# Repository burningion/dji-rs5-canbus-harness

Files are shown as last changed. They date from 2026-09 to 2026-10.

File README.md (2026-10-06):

# DIY RS5 side-port CAN connector - prewired Mill-Max prototype

Build a removable spring-contact adapter on the RS5's electrical RSA/NATO port, with the battery grip attached. The design uses the **prewired Mill-Max 889-22-008-70-501010**, held between two printed parts. The RS5 adaptation retains this part; no different contact block is indicated by the compatibility evidence below. Use an ESP32 with a 3.3 V CAN transceiver, powered from USB for the first version.

**Status: the Mill-Max interface and wired UWB tracking work on the user's RS5.** Confirmed by the user on 2026-10-04: the direct `UWB anchor → ESP32 → Waveshare → Mill-Max pin harness → RS5` connection successfully tracked the tag. The new two-ESP32 wireless path is implemented and software-tested; pairing and following over that radio link still need a hardware check. Camera-enclosure fit, combined-battery operation and charging remain separate, unverified work.

Mill-Max dimensions come from its family drawing; nominal mounting geometry comes from the RS2 community design. The reference pinout, voltage and detect-resistor details below come from DJI R SDK v2.5's RS2 illustration. The working RS5 setup establishes this build's interface, but is not a measurement of accessory VCC or every mechanical tolerance. Keep the proven harness wiring and termination when adding wireless.

Geometry validation: base and cover each export as one closed solid; the combined print plate contains two closed solids. OpenSCAD's solid intersection between the assembled holder and the nominal Mill-Max connector envelope is empty (no solid interference). See [mesh checks](design/mesh-checks.json). This check covers the nominal connector geometry, not the RS5 or manufacturing tolerances.

## UWB through the camera and RS5 ESP32s

The intended wireless path is implemented, with the **RS5-body ESP32 as master** and the camera ESP32 as an optional UWB peripheral:

```text
Subject tag --UWB--> camera-mounted STM32 anchor
  --short UART TXD1/GND--> camera ESP32 (rs5_anchor_radio)
  --paired ESP-NOW radio--> RS5-body ESP32 (rs5_wireless_control)
  --GPIO5 TX / GPIO6 RX--> Waveshare SN65HVD230
  --CAN-H / CAN-L--> Mill-Max harness --> RS5
```

The camera ESP32 reads the anchor on **RX/GPIO38 at 115200 baud** and relays measurements. The body ESP32 runs the existing tracking controller and sends DJI commands over **1 Mbit/s CAN**. ESP-NOW needs no router. Move the anchor's UART/ground connection to the camera ESP32; keep the working body-side Waveshare/Mill-Max circuit. The camera and body have separate power, with no UART, power or ground cable crossing the moving axes. See [wireless wiring and power](firmware/WIRELESS_UWB.md).

The master polls the paired camera every 50 ms and owns tag selection, tracking, motion limits and all CAN commands. Manual mouse/PS4 control works with the camera off, absent, or not yet paired. After the one-time pairing below, powering the camera and tag automatically makes their reports available to the master; no body reflash or mode change is needed on each connection. Control Desk shows **NO UWB**, **TAG DETECTED**, then **TAG LIVE** once the selected tag has a valid fix. Detection offers follow but never starts it or takes over manual control. Losing UWB stops active follow; manual control remains available, and recovery requires a fresh follow action.

**The body still uses USB to the existing Control Desk.** It boots disarmed; apply your tag settings, wait for TAG LIVE, then press PS4 **X** or **Start UWB follow**. This firmware does not start autonomous follow when powered on. The camera ESP32 can run without a USB host. The Makerfabs anchor and tag keep their existing factory firmware and binding.

## Flash both ESP32s

Both targets are **Adafruit Feather ESP32-S3, 8 MB flash / No PSRAM**, using **esp32 by Espressif Systems 3.3.11**. Keep the full repository layout because the sketches include shared files.

| Physical board | Sketch to flash |
| --- | --- |
| On the moving camera, beside the UWB anchor | [rs5_anchor_radio.ino](firmware/rs5_anchor_radio/rs5_anchor_radio.ino) |
| On the RS5 body: master, connected to Waveshare CAN | [rs5_wireless_control.ino](firmware/rs5_wireless_control/rs5_wireless_control.ino) |
| Original single-ESP32 wired setup, if restoring it | [rs5_manual_control.ino](firmware/rs5_manual_control/rs5_manual_control.ino), on the body ESP32 |

**First-time pairing takes two uploads per ESP32:** first discover their MAC addresses, then generate the shared pairing file and rebuild/upload both. Without `firmware/shared/WirelessConfig.h`, both wireless sketches run for MAC discovery with `radio_ready=0`; UWB radio operation is disabled. If that file already exists for these exact two boards, keep it and go directly to the configured builds/uploads.

### 1. Prepare the tools and identify the ports

Run commands from the repository root. With [Arduino CLI installed](https://arduino.github.io/arduino-cli/latest/installation/), install the tested core if needed:

```sh
arduino-cli core update-index --additional-urls https://espressif.github.io/arduino-esp32/package_esp32_index.json
arduino-cli core install esp32:esp32@3.3.11 --additional-urls https://espressif.github.io/arduino-esp32/package_esp32_index.json
arduino-cli board list
```

Connect each Feather through its own USB-C connector, one at a time, and label it **camera** or **body**. Replace `CAMERA_FEATHER_PORT` and `BODY_FEATHER_PORT` below with their actual ports (for example `/dev/cu.usbmodem...` on macOS). Do not select the Makerfabs anchor's port. Close Control Desk's serial connection and any serial monitor before uploading. For flashing, leave the RS5 powered off; neither sketch automatically starts motion.

### 2. Build, flash and read each MAC address

**Camera ESP32:**

```sh
arduino-cli compile \
  --fqbn esp32:esp32:adafruit_feather_esp32s3_nopsram --warnings all --clean \
  --build-path "$PWD/tmp/build-rs5_anchor_radio" \
  --output-dir "$PWD/tmp/rs5_anchor_radio" firmware/rs5_anchor_radio
arduino-cli upload \
  --fqbn esp32:esp32:adafruit_feather_esp32s3_nopsram \
  --port CAMERA_FEATHER_PORT --input-dir "$PWD/tmp/rs5_anchor_radio" \
  firmware/rs5_anchor_radio
arduino-cli monitor --port CAMERA_FEATHER_PORT --config baudrate=115200
```

Record the `camera mac=AA:BB:CC:DD:EE:FF` address printed once per second. Close the monitor with Ctrl+C.

**RS5-body ESP32:**

```sh
arduino-cli compile \
  --fqbn esp32:esp32:adafruit_feather_esp32s3_nopsram --warnings all --clean \
  --build-path "$PWD/tmp/build-rs5_wireless_control" \
  --output-dir "$PWD/tmp/rs5_wireless_control" firmware/rs5_wireless_control
arduino-cli upload \
  --fqbn esp32:esp32:adafruit_feather_esp32s3_nopsram \
  --port BODY_FEATHER_PORT --input-dir "$PWD/tmp/rs5_wireless_control" \
  firmware/rs5_wireless_control
arduino-cli monitor --port BODY_FEATHER_PORT --config baudrate=115200
```

Type `help` and press Enter. Record the `body mac=AA:BB:CC:DD:EE:FF` address, then close the monitor. These are the **Wi-Fi STA MAC addresses**, not UWB tag IDs or Bluetooth addresses. USB ports can change after flashing; run `arduino-cli board list` again and update the port if needed.

### 3. Pair, then rebuild and flash both again

Replace the MAC placeholders with the two recorded addresses:

```sh
python3 tools/configure_wireless_pair.py --camera CAMERA_STA_MAC --body BODY_STA_MAC
```

This creates ignored `firmware/shared/WirelessConfig.h` with the peer addresses, random encryption keys and channel 6. It refuses to overwrite an existing pairing. Keep this file for subsequent updates to the same pair; only move it aside deliberately when replacing/re-pairing boards. Both builds must use the same file.

**Repeat both compile/upload blocks from step 2 after generating the file.** The `--clean` builds ensure the new pairing configuration is included. Uploading the earlier discovery binaries again will leave the radios disabled.

### 4. Verify the link and enable follow

With both nodes powered, check camera serial output for `radio_ready=1`. In the body's JSON status, the `uwb` object should contain `"transport":"esp-now"` and `"radio_ready":true`. These flags confirm local radio initialization; live tag reports on the body prove measurements cross the wireless link.

Close the serial monitors, power the RS5, and start the existing UI:

```sh
python3 control_ui/server.py
```

Open **http://127.0.0.1:8765**, connect to the **body** ESP32, wait for LIVE RS5 angles, apply your tag ID/direction/offset and **5°/s** follow speed, then wait for **TAG LIVE**. Press PS4 **X** or **Start UWB follow**. Retain the settings that worked in the wired test; confirm the camera turns toward the tag. Test camera power loss/tag loss: follow should stop and require a fresh enable action after reports return. [Control Desk setup and controls](control_ui/UWB_SETUP.md#controls-and-first-follow-test).

### Arduino IDE and upload recovery

In Arduino IDE, install **esp32 by Espressif Systems 3.3.11**, then open the camera or body `.ino` from the table. Select **Adafruit Feather ESP32-S3 No PSRAM** and its USB port. Keep **8MB**, **QIO 80MHz**, **TinyUF2 8MB (2MB APP/3.7MB FATFS)**, **USB-OTG (TinyUSB)**, **USB CDC On Boot: Enabled**, and **Upload Mode: USB-OTG CDC (TinyUSB)**. Upload each discovery sketch and use Serial Monitor at **115200**, with a newline for the body's `help` command. Generate the pairing file with the Python command above, then compile/upload both again; the CLI `--clean` commands above provide a clean rebuild after adding the file.

If a Feather has no upload port, hold **BOOT**, tap **RESET**, release **BOOT**, then select its new port. For CLI upload from the ROM bootloader, add `--board-options UploadMode=default` to the upload command if the TinyUSB reset step fails. Press RESET after uploading from ROM mode, then rediscover the application port. [Adafruit's native-USB upload/recovery guide](https://learn.adafruit.com/adafruit-esp32-s3-feather/using-with-arduino-ide).

## When and how to control the RS5

**Mouse and PS4 control remain built into Control Desk.** The current control path is `mouse / PS4 → Mac browser → USB → RS5-body ESP32 master → Waveshare → Mill-Max → RS5`. The camera ESP32 adds optional UWB measurements; manual control works with it powered off.

1. Power the RS5 and connect the **body ESP32** to the Mac by USB. Run `python3 control_ui/server.py`, open **http://127.0.0.1:8765**, select its port and click **Connect**. Wait for **LIVE** RS5 angles. Keep the browser page visible and focused while controlling.
2. For PS4 control, connect the DualShock 4 to the **Mac** with a USB data cable, or hold **SHARE + PS** until its light flashes and select **DUALSHOCK 4 Wireless Controller** in macOS Bluetooth settings. Click the browser page, press a controller button, then release L1 and X before starting. [Detailed controller setup](control_ui/README.md#pair-the-ps4-controller).
3. Use the controls below. Detection, connection and power-up never start movement; each start needs a fresh operator action.

| Action | When available | How to use it |
| --- | --- | --- |
| Mouse pan/tilt | LIVE RS5 angles; UWB is optional | Hold/drag the pad or hold a direction button; release to stop |
| PS4 pan/tilt | LIVE RS5 angles and controller detected | Hold **L1 + left stick**; release L1 to stop |
| UWB pan follow | Applied tag settings and **TAG LIVE** | Press **X** or **Start UWB follow**; press again to stop |
| Stop | During manual control or follow | **Circle**, **Space**, or **Escape** |
| Change from follow to manual | During follow | L1 or mouse cancels follow; release, then hold again to steer |
| Restart after a lost tag or connection | Connection restored; TAG LIVE again for follow | Release controls, then make a fresh manual gesture or X/button press; no automatic restart |

The manual speed slider is **1–60°/s**, initially **10°/s**. UWB follow has its own **1–30°/s** limit, initially **5°/s**, and controls pan only. For UWB, power the paired camera node and tag, enter the detected short tag ID, apply direction/center/speed settings, and wait for TAG LIVE. **TAG DETECTED alone does not enable follow.** Settings must be reapplied after a body reset or page reload. Start with a small tag offset and verify steering toward it. [UWB setup, calibration and controls](control_ui/UWB_SETUP.md#controls-and-first-follow-test).

To use the expanded 30°/s follow range, rebuild/reflash the **body ESP32**, restart the Control Desk server and reload the page. Older body firmware rejects settings above 15°/s; the camera relay needs no change. Preserve the pair's existing configuration when rebuilding. The former ceiling was a conservative bench-test setting; the starting value remains 5°/s. [Speed setting and update details](control_ui/UWB_SETUP.md#tracking-behavior).

The current firmware requires the active USB/Control Desk session for both manual control and follow. Closing/hiding the page, losing focus, or losing controller/input/USB communication stops motion; returning does not resume it automatically.

### Future direct PS4 pairing

**Direct PS4-to-ESP32 Bluetooth control is not implemented.** The present Feather **ESP32-S3 cannot pair natively with a DualShock 4**: the controller uses Bluetooth Classic (BR/EDR), while the S3 supports Bluetooth LE only. This needs different/additional radio hardware, not just a pairing setting. [Bluepad32 compatibility explanation](https://bluepad32.readthedocs.io/en/latest/FAQ/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), [Espressif S3 Bluetooth support](https://docs.espressif.com/projects/esp-idf/en/stable/esp32s3/api-reference/bluetooth/index.html).

For a future extension that keeps the working S3/CAN master, add an **original ESP32 with Bluetooth Classic**, running Bluepad32 as a gamepad receiver, and pass its input to the master over a short local UART connection. Another option is to replace the body board with an original ESP32 and port the firmware/pin mapping. The existing S3 binaries cannot be flashed onto that replacement. These are proposed designs, not existing firmware features.

Either approach needs firmware support for controller pairing and input, local tag/settings management, and choosing between UI and direct-controller input. The master should retain L1-to-move, X-to-toggle-follow, Circle-to-stop, input timeouts and explicit restart after disconnection. Computer-free operation also needs a direct-controller input lease in place of today's required USB/browser lease; simply removing that requirement would not implement controller-loss handling. The camera remains an optional UWB peripheral. [More on future direct control](control_ui/README.md#future-direct-ps4-control).

## Changes from RS2

- **Use the one electrical RSA/NATO port.** The RS5 manual identifies it as item 17, next to the joystick-mode switch (item 25). The other side's NATO rail, item 12 near the power button, has no charging or communication. Identify the exposed contacts rather than relying on an ambiguous left/right description.
- **Retain Mill-Max 889-22-008-70-501010 and the ESP32/CAN-transceiver circuit.** DJI lists the same Focus Wheel, supplied with two M4 screws, for RS2 and RS5. That is strong evidence of a compatible legacy RSA interface; it is not a dimensional drawing for this DIY part.
- **No evidenced geometry change.** The RS5 base and cover deliberately retain revision-B dimensions. The new RS5 files, fit gauge and port instructions make that carry-over explicit. Confirm 19.85 mm nominal screw spacing, eight-pad alignment, pad recess, screw depth and cable-ear clearance on your RS5; those values were not measured on one here.
- **Keep USB power for the controller.** Leave both accessory VCC leads insulated. The older SDK's 8 V accessory output is not an RS5-specific voltage guarantee; the RS5 battery's 11.2-17.8 V specification is a different circuit.
- **The electrical port is occupied by this adapter.** The RS5 Electronic Briefcase Handle cannot use that same mounting point simultaneously. DJI's special warning about fitting that new handle to older gimbals does not change the legacy Focus Wheel compatibility evidence.

## Files

- [Wireless camera-to-body electronics](firmware/WIRELESS_UWB.md): camera-side STM32 anchor plus its own Feather ESP32-S3 share one 3.7 V / 500 mAh battery; paired ESP-NOW sends measurements to the body-side Feather/CAN controller. Includes firmware, Feather USB charging, a direct positive-lead battery switch and pairing instructions. Revision G models the stacked Feather/STM32 mounts and Feather charging port; charging with the anchor load and other hardware behavior remain unverified.

- [Print both parts](design/rs5-millmax-print-plate.stl): base and rear cover, already oriented for printing at 100% scale in millimeters.
- [Base STL](design/rs5-millmax-base.stl) and [rear cover STL](design/rs5-millmax-cover.stl), if printing separately.
- [RS5 OpenSCAD entry point](design/rs5-millmax.scad), using [shared adjustable geometry](design/rsa-millmax.scad): select `assembly` or `exploded` for inspection. Requires OpenSCAD 2021.01 or newer.
- [1.2 mm fit gauge](design/rs5-fit-gauge.stl): print first; hold against the unpowered port by hand, without contacts or screws. It checks the footprint and alignment, not pad depth or preload.
- [Prototype preview](design/carrier-preview.png): base, cover, and assembled connector.
- [RS5 carrier alias](design/rs5-carrier.stl) is the same two-part print plate. The original [RS2 entry point](design/rs2-millmax.scad) and RS2 STLs remain available; the default holder geometry is unchanged.
- [Archived PRECI-DIP design](design/archive/rs2-precidip-rev-a.scad): superseded; its dimensions are not for Mill-Max.
- [Original community STL](references/rileyharmon-rs2-connector.stl): provenance for the mounting dimensions only.
- [RS5 wiring diagram](design/wiring.png), with the inherited-pinout limitation marked.
- [Feather ESP32-S3 CAN test firmware](firmware/README.md): Arduino listen-only monitor, GPIO5 TX / GPIO6 RX, serial diagnostics and flashing instructions for the Adafruit 8 MB / no-PSRAM board.
- [Finite RS5 motion bench test](firmware/rs5_can_motion_test/README.md): telemetry-gated three-cycle pan test, verified on the connected RS5 on 2026-09-28; no automatic motion on boot.
- [RS5 Control Desk](control_ui/README.md): local mouse / PS4 controller UI with **X-to-toggle UWB follow** ([connection layout and setup](control_ui/UWB_SETUP.md)) for analog pan and tilt, 1–60°/s speed selection with no added travel limits, live angles, and automatic hold-to-move with release-to-stop; companion [manual-control firmware](firmware/rs5_manual_control/README.md).
- [Standalone Makerfabs UWB camera-tracking prototype](firmware/rs5_uwb_tracker/README.md): camera-mounted AoA anchor, subject-carried tag, UART on Feather RX/GPIO38; preview by default, optional manually armed RS5 pan control. Compiled and host-tested; physical operation remains unverified.
- [Makerfabs tag pocket enclosure](design/mauwb-tag/README.md): revision D adds the anchor's exact 13.5 × 8.4 mm rocker opening on the BAT-connector side, with a switch fit coupon. Same case dimensions; rev C rear cover and battery shield can be reused. Removable 500 mAh battery, external charging, no soldered headers. Vendor PCB dimensions with provisional component heights.
- [Camera-top UWB anchor enclosure](design/mauwb-anchor/README.md): revision G mounts the Feather below the STM32/antenna, adds Feather USB-C access, and preserves the exact 13.5 × 8.4 mm rocker opening and 26.48 mm cage-hole spacing. Both boards have rear M2 screw mounts; Feather front pins and STM32 front-edge keepers provide support. Body 87.7 × 58 × 41.1 mm, overall height 72.81 mm. The rocker switches battery positive directly. **Physical fit/RF and charging with the anchor load are unverified.**
- [RS5 port illustrations](references/dji-rs5-ports.png) and [overview](references/dji-rs5-overview.png), from pages 17 and 6 of the [RS5 user manual](references/dji-rs5-user-manual.pdf).
- [DJI's illustrated pinout](references/dji-sdk-pinout.png), from PDF page 21 / printed page 19 of the [SDK](references/dji-r-sdk-v2.5.pdf).

## Electrical design

The user's Waveshare/Mill-Max wiring has already worked for RS5 control and wired tag tracking. Preserve that harness. For a new or rebuilt harness, identify every contact before applying power; the reference below is inherited from the older SDK, and a fit gauge cannot identify electrical signals.

The inherited RSA contact layout has **eight pads in two rows of four**; check this against the exposed RS5 port. DJI assigns six signal numbers because power and ground each appear twice. The numbers below are DJI's signal labels, not sequential positions in an eight-pin header.

| DJI label | Signal | Connection in this build |
| --- | --- | --- |
| 1, two pads | VCC, nominal 8 V in the older SDK | Leave disconnected; individually insulate both unused wire ends |
| 2 | CAN-L | CAN-L on the transceiver |
| 3 | SBUS_RX | Leave disconnected |
| 4 | CAN-H | CAN-H on the transceiver |
| 5 | AD_COM | 47 kOhm resistor to ground at the controller's terminal block |
| 6, two pads | GND | Transceiver ground and ESP32 ground; one ground contact suffices for this signal-only build |

DJI specifies a 10-100 kOhm accessory-detect pull-down; 47 kOhm is our choice within that range. The SDK explicitly links detection to enabling port power. It does not establish that the resistor is necessary for CAN alone. Do not substitute a direct short.

The **legacy RS2 SDK illustration**, viewed facing the gimbal contacts in its illustrated orientation, gives this arrangement. This is a reference for tracing signals, not a verified upright view of the RS5:

```text
        GND       AD_COM     SBUS_RX     8 V
        GND       CAN-H      CAN-L       8 V
```

Use the [illustrated DJI reference](references/dji-sdk-pinout.png) to understand its viewing direction. Do not transfer its pictured RS2 body orientation directly to RS5. The older SDK's remark about two rotationally symmetric side ports applies to RS2; RS5 has only one electrical RSA port. Confirm the RS5 ground column against a known ground with the battery and USB disconnected; if orientation cannot be established, stop before energizing and obtain an RS5-specific reference. The adapter's mating face also reverses left/right relative to a face-on view of the gimbal. Mark the ground column and identify each wire by continuity to its contact. The Mill-Max wires are all black; do not infer signal identity from wire color or the order of the loose ends.

Recommended controller interface:

```text
ESP32 TWAI TX ---- transceiver D / TXD
ESP32 TWAI RX <--- transceiver R / RXD
ESP32 3V3 ------- transceiver VCC
ESP32 GND ------- transceiver GND ------- RS5 GND
                  transceiver CANH ------ RS5 CAN-H
                  transceiver CANL ------ RS5 CAN-L

RS5 AD_COM ------- 47 kOhm ------- RS5 GND
```

An SN65HVD230 breakout is suitable: it operates from 3.3 V and supports 1 Mbit/s. Use high-speed mode (RS low, per TI's datasheet), local supply decoupling, and check whether the module already contains a termination resistor. ESP32 GPIOs cannot connect directly to CAN-H/L. ESP32's built-in TWAI controller supplies the controller function; the transceiver supplies the electrical interface. Select GPIOs appropriate to your particular ESP32 board. A classic Arduino Uno instead needs a CAN controller as well as a transceiver.

For the **Adafruit Feather ESP32-S3, 8 MB flash / no PSRAM**, all body-side sketches use **pin 5 (GPIO5) to Waveshare CAN TX** and **pin 6 (GPIO6) from Waveshare CAN RX**, with the Feather's 3V output and common GND. GPIO4 is the Feather's I2C SCL line and is left available for its onboard devices and STEMMA QT. The [CAN monitor](firmware/README.md) is a passive diagnostic; the wired and wireless control sketches use normal 1 Mbit/s CAN and send DJI commands when operated through Control Desk.

The connector has approximately 203 mm (8 inches) of 24 AWG leads. Identify and gently twist the CAN-H/L pair, keeping a short transition at the connector. Run ground alongside the pair. The detect lead goes to a terminal with the 47 kOhm resistor to ground. Bare lead ends can connect to a suitable screw-terminal CAN breakout; the pogo block itself needs no soldering or crimping. Anchor the insulated wires to the rear cover's cable-tie ear, allowing a gentle bend after they leave the holes. Individually insulate unused leads.

## Parts

| Quantity | Part | Selection notes |
| --- | --- | --- |
| 1 each | Printed base and rear cover | PLA for fit checks; PETG or ASA for the working parts |
| 1 | Mill-Max 889-22-008-70-501010 | Prewired, 8 contacts, 2x4, 2.54 mm grid; Mouser stock number 575-8892200870501010 |
| 2 | M4 screws and small washers | Both layers total 11.85 mm nominal, plus washers; choose length after measuring RS5 thread depth |
| 1 | 47 kOhm resistor | Accessory detect to ground |
| 1 | SN65HVD230 breakout | 3.3 V supply, high-speed mode, accessible termination |
| 1 | ESP32 development board | USB powered initially |
| 1 | 120 Ohm resistor and jumper | Fit only if required by the measured bus termination |
| As needed | Terminal connections, insulating sleeves/heat-shrink, small cable tie | No glue is required to retain the pogo block |

Order link: [Mill-Max 889-22-008-70-501010 at Mouser](https://www.mouser.com/ProductDetail/Mill-Max/889-22-008-70-501010?qs=Rp5uXu7WBW9JMC9qfc9GZw%3D%3D). The 889-22 version has spring contacts; the 889-10 version is a different target-contact product.

The rear cover captures the plastic housing and encloses each exposed rear metal section in its own tunnel. All eight wires pass straight through the cover. The housing is retained by the two M4 mounting screws through both printed layers. The locating pins align the cover; they do not carry the spring load.

## Mill-Max dimensions used

See the [manufacturer's family drawing](references/millmax-889-family.pdf) and [enlarged detail](references/millmax-889-drawing-detail.png). The PDF title names the 14-position part; the drawing is explicitly for **889-22-0XX-70-501010** and gives housing length as `number of pins x 0.100 inch / 2`. Applying that formula to 8 contacts gives 10.16 mm. The drawing's inch dimensions are used in CAD to avoid accumulating rounding differences.

| Feature | Drawing dimension | CAD value |
| --- | --- | --- |
| Contact pitch and row pitch | 0.100 in | 2.540 mm |
| Housing length, eight contacts | 8 x 0.100 in / 2 | 10.160 mm |
| Housing width | 0.200 in | 5.080 mm |
| Housing thickness | 0.110 in | 2.794 mm |
| Tip to rear shoulder | 0.283 in | 7.1882 mm |
| Rear shoulder to start of wire insulation | 0.158 in | 4.0132 mm |
| Housing rear to start of wire insulation | 0.204 in, +/-0.010 | 5.1816 mm, +/-0.254 |
| Tip diameter / front fixed barrel | 0.042 / 0.059 in | 1.067 / 1.499 mm |
| Rear shoulder / crimp barrel diameter | 0.067 / 0.062 in | 1.702 / 1.575 mm |
| Maximum spring stroke | 0.055 in | 1.397 mm |

**The 7.19 mm dimension is not measured from the plastic housing's back face.** The correct tip-to-housing-rear distance is `7.1882 + 4.0132 - 5.1816 = 6.0198 mm`. This distinction matters when setting spring compression. The fixed front barrels also need larger holes than the earlier PRECI-DIP tip apertures.

## Mechanical design and fit

The original STL measures approximately 19.80 x 28.85 x 8.00 model units, with 4.3 mm mounting bores about 19.85 mm apart. STL does not encode units; use millimeters as a starting assumption. These are measurements of a community mesh, **not a DJI dimensioned drawing**. The original mesh passed an edge-sharing check for a closed surface.

The RS5 prototype keeps the revision-B mounting footprint but uses a 5.420 mm base plus a 6.432 mm rear cover, approximately **11.85 mm total**. The optional cable-tie ear adds 9 mm to one side of the cover; maximum width is 28.80 mm with the ear enabled. Check its clearance on the RS5; `strain_relief_ear=false` produces a compact 19.80 mm-wide cover.

When mounted and the contacts are loaded, the rear of the connector's plastic housing rests against the cover's inner face. That face sets the spring preload. The front pocket has 0.20 mm axial clearance so the cover does not squeeze a slightly oversize housing. The block can move forward slightly while unmounted; this is intentional. Tighten the M4 screws only enough to close the printed layers and seat the holder, not to compress the plungers to their limit.

Important parameters in `design/rsa-millmax.scad` (or override using OpenSCAD `-D`):

| Parameter | Default | What to verify |
| --- | --- | --- |
| `mount_pitch` | 19.85 mm | Actual M4 hole center spacing |
| `contact_offset_x/y` | 0.02 / 0.22 mm | Contact-array center relative to mounting-hole midpoint |
| `pad_recess` | 0 mm placeholder | Distance from carrier support surface down to contact-pad surface |
| `target_compression` | 0.60 mm | Engineering starting target, subject to actual contact travel and tolerances |
| `pocket_clearance` | 0.40 mm total | Actual pocket fit around the housing, allowing its +/-0.13 mm dimensional tolerance |
| `front_aperture_diameter` | 1.95 mm | Printed holes clear the fixed 1.50 mm front barrels |
| `wire_tunnel_diameter` | 2.10 mm | Printed holes clear rear shoulders and actual wire insulation |
| `axial_clearance` | 0.20 mm | Forward housing play when unmounted |
| `rear_insulation_overlap` | 1.25 mm | Cover extends beyond bare crimp sections onto insulated leads |

The model uses `base_thickness = tip_to_housing_rear - pad_recess - target_compression`. At the placeholder zero recess and 0.60 mm compression, the base is 5.4198 mm thick and the front web is 2.4258 mm. A positive measured pad recess makes the required base thinner. With the housing against the rear cover, free tips extend 0.60 mm beyond the mounting plane; forward play can increase that protrusion by 0.20 mm when unmounted. Measure compression in the mounted condition. The 0.60 mm target leaves nominal room within the 1.397 mm stroke, but component, print, and gimbal tolerances must still be checked together.

Both provided STLs are already oriented for printing: base mating face down; rear cover outer face down, blind locating sockets up. Start with 0.15-0.20 mm layers, four or five perimeters, and 40-60% infill. These are suggested settings, not printer-validated settings. No support is intended. Inspect the slicer preview for the 0.44 mm webs between cover tunnels. Deburr holes and remove first-layer lips. Use plain insulating filament, without carbon or metal additives.

Assembly:

1. Remove the battery grip and disconnect other power. Identify electrical port 17 next to the joystick-mode switch and remove its contact cover. Hold the thin fit gauge against it by hand; check both mounting centers and all eight aperture centers. Do not install screws through the thin gauge. Then fit the empty full-thickness base and cover. Their flat mating faces must close without force. The asymmetric locating pins permit only one cover orientation.
2. Check M4 hole spacing, contact aperture alignment, pad recess, and cable-ear clearance. Adjust SCAD parameters if needed. Do not scale the whole STL: that changes contact pitch. Select M4 screw length using the 11.85 mm assembled thickness, washers, and measured safe thread engagement.
3. Before connecting the wire ends to anything, label each black lead by continuity to its spring contact. Mark the intended gimbal orientation. Thread all eight free wire ends through the corresponding cover holes, entering its INNER face (the face with the two blind locating sockets).
4. Slide the cover along the leads toward the connector, keeping their order. Each bare metal crimp enters its own tunnel. Check smooth passage without forcing, scraping insulation, or bending contacts. Correct any undersize printed holes with the parts off the connector.
5. Place the pogo block in the base pocket, spring tips facing out through the eight apertures. Close the cover onto the locating pins. The connector is captured between the parts without adhesive. Hold the layers together while fitting the M4 screws to the unpowered RS5.
6. Verify that all tips land centrally and have spring travel remaining when the holder is seated. Tighten lightly; do not draw misaligned parts together with the screws. If compression is wrong, adjust `pad_recess` or the base geometry and reprint the base.
7. Gently route the insulated wires to the cover ear and secure with a small cable tie. Avoid a sharp bend or pull at the crimp-to-insulation transition. Twist H/L and connect H, L, ground, and the detect-resistor circuit at the controller. Individually insulate all unused wire ends.

## Termination and first electrical checks

Provide selectable termination, not an unconditional extra resistor. Conventional high-speed CAN uses 120 Ohms at each end, giving roughly 60 Ohms between H and L with all power removed. The DJI documents checked here do not specify the effective termination at your assembled accessory port.

With the battery removed and USB/other supplies disconnected, measure H-to-L resistance through the finished wiring with your extra termination disabled:

- Around 60 Ohms: two conventional terminators are already present; leave the extra one off.
- Around 120 Ohms: typically one terminator is present. For a two-end setup, add 120 Ohms at the otherwise unterminated controller end and recheck.
- Open, unusually low, unstable, or substantially different: investigate contact continuity, module resistors, and actual bus topology before choosing termination. Do not just add resistors until the meter reads 60.

Also verify the 47 kOhm detect path, absence of unintended shorts to the VCC pads, and H/L/ground continuity. Fit and remove the adapter with power off so contacts cannot sweep across adjacent power pads.

The inherited SDK settings are **Classical CAN, 1,000,000 bit/s, standard 11-bit IDs**. The 2026-09-28 [RS5 bench test](firmware/rs5_can_motion_test/README.md#hardware-result--2026-09-28) verified joint queries with controller TX **0x223** and SDK replies on **0x222**, followed by three small yaw cycles. Unsolicited traffic on **0x426** was also observed; it is not decoded by these sketches. DJI SDK messages span multiple CAN frames and use DJI's packet framing and CRCs; arbitrary CAN payloads will not control the gimbal. This test does not validate the accessory supply voltage or all mechanical dimensions.

Start by observing traffic, then use a documented read-only SDK query. Listen-only mode does not acknowledge frames, and a quiet bus alone does not prove the connector failed. An otherwise solitary transmitter may retry without an acknowledging node. Once wiring and bitrate are confirmed, normal CAN mode can acknowledge while your application sends only queries. Clear the gimbal's motion area before any motion-control test.

## Sources and attribution

- [DJI RS SDK download page](https://www.dji.com/rs-sdk): rechecked 2026-09-18; explicitly lists RS5. Still links `SDK documentation_20210729.zip` and the older external-interface PDF. Local SDK v2.5 and diagram were downloaded 2026-09-16. The pinout and electrical parameters above are from those legacy documents, not an RS5-specific electrical drawing.
- [DJI RS5 user manual](https://dl.djicdn.com/downloads/DJI_RS_5/20260115/UM_2/DJI_RS_5_User_Manual_en.pdf): pages 6 and 17 distinguish the electrical RSA/NATO port from the mechanical-only NATO rail.
- [DJI Focus Wheel listing](https://store.dji.com/product/ronin-s-focus-wheel): lists RS5 and RS2 compatibility and two M4 mounting screws; basis for inferring a shared RSA mating interface.
- [DJI RS5 support FAQ](https://www.dji.com/support/product/rs-5): the new Electronic Briefcase Handle cannot be fitted to older models because of its signal-blocking structure. This is a handle-specific change; it does not establish different dimensions for the legacy Focus Wheel interface.
- [Riley Harmon: DJI Ronin RS2/3 Pro Log and Replay](https://github.com/rileyharmon/DJI-Ronin-RS2-Log-and-Replay): original STL and suggested spring-contact part. Credit also to Cornelius von Einem and Casey Basichis as named in its README. Original STL and this CAD derivative are **CC BY-NC 4.0**; the derivative changes are listed in the SCAD header. [Original README](references/rileyharmon-README.md), [license terms](https://creativecommons.org/licenses/by-nc/4.0/).
- [Mill-Max 889 family drawing, hosted by DigiKey](https://mm.digikey.com/Volume0/opasdata/d220001/medias/docus/6448/8892201470501010.pdf): mechanical dimensions and tolerances; local copy linked above.
- [Mill-Max manufacturer announcement](https://www.heilind.eu/page/wp-content/uploads/pr704_-_pre-wired_spring-loaded_target_connectors_ms.pdf): 889-22 prewired family, 24 AWG wire and 8-inch lead length.
- [Mouser exact-part listing](https://www.mouser.com/ProductDetail/Mill-Max/889-22-008-70-501010?qs=Rp5uXu7WBW9JMC9qfc9GZw%3D%3D): exact 8-contact part and order number.
- [Espressif TWAI documentation](https://docs.espressif.com/projects/esp-idf/en/v5.4/esp32/api-reference/peripherals/twai.html): external transceiver requirement and CAN controller operation.
- [Texas Instruments SN65HVD230](https://www.ti.com/product/SN65HVD230): transceiver supply, speed, and operating modes.
- [Texas Instruments CAN termination reference](https://www.ti.com/tool/TIDA-01238): termination at the two farthest nodes.

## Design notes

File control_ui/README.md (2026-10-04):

# RS5 Control Desk

A local browser UI for manual **pan and tilt**, using a mouse or a PS4 / DualShock 4 controller, plus **X-to-toggle UWB pan follow** using the Makerfabs STM32 AoA kit. See the [UWB wiring and setup guide](UWB_SETUP.md). Roll speed is always zero. The USB-connected Feather talks to the RS5 through the existing Waveshare CAN wiring. The controller connects to the **Mac**, by USB or Bluetooth.

The **RS5-body ESP32 is the master**. Manual control works with the camera UWB node absent or off. Once paired, the camera ESP32 supplies measurements automatically when available. The UWB panel shows **NO UWB**, **TAG DETECTED**, or **TAG LIVE**; only a fresh selected tag enables follow. Camera detection/loss does not take over a manual gesture, and detection never starts movement. [Flash and pair both ESP32s](../README.md#flash-both-esp32s).

## Start

Requires Python 3.11+ with pyserial and aiohttp. Both were already installed on this Mac. On a new machine, use a virtual environment and `python3 -m pip install -r control_ui/requirements.txt`.

From the repository root:

```sh
python3 control_ui/server.py
```

Open **http://127.0.0.1:8765** in Chrome or Edge. The app binds only to the local machine. Close other serial monitors; one browser tab owns the connection at a time. No internet or external frontend assets are needed.

1. Choose the Feather USB port and click **Connect**. Wait for **LIVE** angles. Release the mouse and L1 once after connecting.
2. **Mouse:** hold and drag the circular pad, or hold a direction button. Movement starts from that gesture; release to stop.
3. **PS4:** hold **L1** and move the **left stick**. Movement starts automatically while L1 is held. Release L1 to stop. The stick remains analog: gentle deflection gives slow movement and full deflection reaches the selected maximum.
4. Manual control has **no Enable button, Stop button, or input-mode selector**. Both devices are available together. The first held control owns the gesture; release both before switching to avoid a jump to an already-held second input.
5. **Space**, **Escape**, or PS4 **Circle** also stops. After a stop, focus loss, disconnect, or fault, release the controls and hold again. Connecting, recovering a connection, or leaving a stick displaced never starts movement by itself.

For UWB, configure the tag in the **UWB FOLLOW** panel and wait for **TAG LIVE**, then press **X** or click **Start UWB follow**. X toggles; Circle/Space/Escape stops. L1 or mouse cancels follow; release and hold again for manual control. Tag loss disarms and requires a fresh X press after reacquisition. Follow defaults to 5°/s with a separate 30°/s cap. The [setup guide](UWB_SETUP.md) includes the camera-mounted anchor wiring and direction calibration.

Keep the balanced gimbal supported, unlocked, and clear of cables/obstructions, with its physical power control accessible.

The maximum-speed slider runs from **1 to 60 degrees/second**, initially **10**. The stick has a 12% radial dead zone and a 1.6-power response for fine movement near center. Diagonal input is normalized. At 50% stick deflection and a 60°/s maximum, speed is approximately 15.6°/s. Mouse-pad displacement is also proportional; the direction buttons use the selected maximum. Changing speed or direction reversal during a gesture stops it; release and hold again to use the new setting.

Use **Reverse pan / Reverse tilt** if the physical direction feels opposite to the labels. The previous RS5 bench test found that positive yaw-speed requests decrease reported joint yaw. The UI reports raw DJI joint angles; it does not assume a command sign matches the reported angle sign or run position correction.

If the app says **CAN connection stopped**, the Feather has latched a bus fault. Ensure the RS5 is on and the connection is sound, click **Disconnect**, press the Feather's **Reset** button, then **Connect** again. A server restart or page refresh alone does not clear this device-side fault. The UI distinguishes a CAN fault from missing firmware, stale USB telemetry, and a gimbal that is not answering queries. Read-only diagnostics are available at `http://127.0.0.1:8765/api/status` without taking control away from the open UI.

## Pair the PS4 controller

Use a USB data cable, or hold **SHARE + PS** until the controller light flashes, then pair **DUALSHOCK 4 Wireless Controller** in macOS Bluetooth settings. Click the browser page and press a controller button so the browser exposes it. The controller is detected automatically; release L1 once after connecting. The first detected DualShock is preferred, otherwise the first connected controller; the app won't switch controllers while enabled.

Only the browser's **standard** gamepad mapping is accepted. An unknown mapping disables controller operation instead of guessing which button is L1. Chrome/Edge are the suggested first browsers to try. If the controller is not shown, confirm macOS pairing/data-cable operation and press a button while this page has focus. A USB cable is the simplest way to isolate a Bluetooth issue.

Sources: [Sony's DualShock 4 pairing instructions](https://www.playstation.com/en-us/support/hardware/ps4-pair-dualshock-4-wireless-with-pc-or-mac/), [MDN Gamepad API and standard mapping](https://developer.mozilla.org/en-US/docs/Web/API/Gamepad_API/Using_the_Gamepad_API). The ESP32-S3 supports Bluetooth LE but not Bluetooth Classic ([Espressif](https://docs.espressif.com/projects/esp-idf/en/v5.2/esp32s3/api-guides/bluetooth.html)); this implementation routes the controller through the Mac.

## Future direct PS4 control

**Not implemented:** the current PS4 connection goes through the Mac/browser and USB. DualShock 4 requires Bluetooth Classic, which our Feather ESP32-S3 lacks. Bluepad32 supports it on the **original ESP32**; installing the library on an S3 does not add that radio capability. [Bluepad32 controller/chip compatibility](https://bluepad32.readthedocs.io/en/latest/FAQ/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).

The proposed extension is a small original-ESP32 gamepad receiver connected by UART to the existing body master. It would supply live button/stick input while the master continues to own CAN and optional UWB tracking. Replacing the body S3 with an original ESP32 is also possible in principle, but requires porting the firmware and checking pin assignments, USB behavior and simultaneous Bluetooth/ESP-NOW operation.

Computer-free control needs additional firmware: explicit controller pairing, input-source ownership when a UI is also connected, a controller-report timeout, and a way to select/apply the UWB tag and settings without the browser. Preserve L1-to-move/release-to-stop, Circle stop, X follow toggle, fresh tag/telemetry requirements and no automatic restart. Use fresh controller reports to authorize continued operation instead of requiring the current browser/USB lease. A connected Bluetooth state alone is not proof of fresh input. The present builds still require Control Desk; these notes describe future work.

## Travel and stopping

- Firmware caps pan and tilt at **60°/s per axis**; roll command remains zero. It requires three valid, matching CRC-checked joint replies before starting a held gesture.
- **No added software travel limits or starting-angle restrictions.** Pan can cross the reported ±180° seam and keep turning while input is held. Joint replies use the SDK’s full signed 16-bit angle representation, including readings beyond ±180°. Roll requested speed remains zero, without an extra roll-angle excursion stop.
- DJI specifies **360° continuous pan rotation**, with finite mechanical tilt travel of **−112° to +214°** ([RS5 specifications](https://www.dji.com/rs-5/specs)). Removing the app’s limits does not change the gimbal’s own settings or physical clearance. Arrange external camera/USB cables so rotation cannot wind them around an axis; continuous pan on this particular wired setup has not been automatically motion-tested.
- The browser sends current input at about 20 Hz only while visible and focused. Loss of focus, hiding the tab, controller disconnect, or a paused animation loop stops movement. Returning to the page requires a fresh hold; a still-held control cannot resume movement.
- The bridge never generates a motion heartbeat from cached input. It expires incoming input after **250 ms**, rejects expired server tickets / repeated sequence numbers, and allows one controlling tab. Closing the tab stops and closes USB.
- Firmware independently stops after **300 ms** without valid input, **400 ms** without fresh telemetry, USB disconnection, or a loop delay over **100 ms**. It checks expiry before reading buffered commands; session tokens and device-clock stamps prevent old input from restarting motion. A new gesture requires release followed by a fresh held input.
- Normal stop sends zero speeds and releases SDK control. CAN faults clear TX and stop the driver; resetting the Feather is required after fixing the fault. A broken link can prevent stop packets from reaching the gimbal. The older SDK specifies a 0.5-second speed-command expiry, but that fallback has not been physically fault-tested on this RS5. Keep its physical power control accessible.

These are supervised manual controls, not a hardware emergency-stop system. Release-to-stop and keyboard/controller cancellation depend on a working control link.

## CAN and USB reliability

The initial firmware used CAN single-shot mode. Espressif specifies that this disables retransmission even after losing arbitration, so normal bus contention could become a fatal TX failure. The old log combined several fault types and discarded the counters during shutdown, so the exact earlier event cannot be proven from those logs. The updated sketch uses normal CAN arbitration retries, with a **20 ms packet deadline**. A deadline or actual bus/TX/RX fault still clears TX and stops the driver. It preserves the fault mask, bus/TX failure counters, and arbitration count in telemetry. It never automatically restarts motion after a fault. [Espressif TWAI documentation](https://docs.espressif.com/projects/esp-idf/en/v5.0/esp32s3/api-reference/peripherals/twai.html).

The bridge also permits up to **20 ms** for a recently written USB setup/stop message to drain. Previously any nonempty USB output buffer was immediately called congestion, which could reject normal back-to-back startup commands. Persistent backlog is still cleared and rejected; old speed requests are never replayed.

## Firmware

Use [rs5_wireless_control](../firmware/rs5_wireless_control/README.md) on the body master and [rs5_anchor_radio](../firmware/rs5_anchor_radio/README.md) on the camera for wireless UWB. The combined [rs5_manual_control](../firmware/rs5_manual_control/README.md) remains the direct-UART option. The UI requires protocol v2 with a reported 60°/s manual capability; UWB follow also requires the `uwb` capability/status object. Older v2 firmware remains manual-only; it will not enable against older console formats or the earlier 10°/s manual firmware. Boot starts in normal CAN mode (acknowledging frames) with no application commands; Connect starts joint queries. Fresh held mouse/L1 input automatically requests a zero-speed control session, waits for the device to acknowledge it, and then forwards new input; release ends the session. The bridge never generates motion from cached input. The app does not change stored RS5 settings or limits.

## Demo and checks

No hardware needed for a preview; Connect selects a simulated Feather:

```sh
python3 control_ui/server.py --demo --port 8766
```

The preview has an always-visible **PREVIEW MODE** banner and never opens a serial device.

```sh
python3 -m unittest discover -s control_ui/tests -v
node control_ui/tests/input_test.mjs
node control_ui/tests/app_test.mjs
node --input-type=module --check < control_ui/static/app.js
c++ -std=c++17 -Wall -Wextra -Werror -fsanitize=address,undefined -fno-omit-frame-pointer firmware/tests/manual_control_test.cpp -o tmp/manual_control_test
./tmp/manual_control_test
c++ -std=c++17 -Wall -Wextra -Werror -fsanitize=address,undefined -fno-omit-frame-pointer -Ifirmware/tests/manual_stubs firmware/tests/manual_transport_test.cpp -o tmp/manual_transport_test
./tmp/manual_transport_test
c++ -std=c++17 -Wall -Wextra -Werror -fsanitize=address,undefined -fno-omit-frame-pointer -Ifirmware/tests/manual_stubs firmware/tests/uwb_transport_test.cpp -o tmp/uwb_transport_test
./tmp/uwb_transport_test
```

Tests cover analog shaping, dead zones, L1/Circle mapping, zero on release, the 60°/s speed cap, repeated pan wraparound and angles outside the former travel limits, USB/browser input expiry, replay/late-input rejection, single-tab ownership, same-origin access, and a full simulated WebSocket hold/move/release/disconnect lifecycle. A DOM/event fixture runs the actual frontend through mouse and L1 gestures without a browser or hardware. The actual sketch is also exercised against a fake TWAI driver for arbitration retry, deadline expiry, TX clearing, and preserved fault diagnostics. The C++ protocol check uses DJI's independent SDK vector.

For a real, **read-only** check through the running server (close the UI tab first):

```sh
python3 control_ui/check_connection.py --port /dev/cu.usbmodem2101 --log tmp/rs5-ui-query-check.jsonl
```

This sends Connect/Disconnect only, verifies live angles, and asserts movement remains disabled. Browser visual inspection and a physical PS4 controller test require a browser/controller available to the operator; they are not substitutes for the automated tests. Actual 60°/s movement and full-turn operation remain for a supervised hands-on test; the automatic hardware check only reads telemetry.

### Hardware check — 2026-09-28

Manual-control firmware upload and flash hash verification passed. The local UI bridge received 15 validated joint replies with yaw −24.6°, pitch −2.7°, and roll +1.7° at the end of the read-only check. All sampled CAN errors, missed frames, overruns, REC, and TEC were zero. Every sampled state was disarmed with zero pan/tilt requested speed. The check then disconnected and ended queries. Log: `tmp/rs5-ui-query-check.jsonl` (ignored by Git).

Thirteen Python unit/integration checks, Node input-mapping checks, JavaScript syntax validation, and sanitized C++ control/protocol tests passed. No browser backend was available for visual verification, and no physical PS4 input or new manual movement was exercised by the automated check.

A subsequent connection remained unavailable because the Feather reported `REFUSED reset required after CAN fault`. Resetting the Feather restored communication: 15 valid joint replies, zero errors/loss/REC/TEC, and movement disabled. Recovery log: `tmp/rs5-ui-recovery-check.jsonl`. The underlying transient that triggered the latched fault was not captured. The UI now reports this fault explicitly rather than displaying a generic waiting message; diagnostics and message regression checks passed.

### 60°/s and unrestricted software travel update

The operator requested removal of the app's angle limits and a 60°/s maximum. Firmware, bridge, UI, and simulator were updated together; the slider defaults to 10°/s. Fifteen Python tests, Node input tests, JavaScript syntax checks, and sanitized C++ tests passed, including three simulated pan revolutions, reverse wraparound, and SDK joint replies outside ±180°. The firmware was flashed and hash-verified. A read-only check reported protocol v2 and a 60°/s capability, with 15 valid replies and zero errors/loss/REC/TEC while disarmed. Yaw was −10.0°, roll +1.7°, and pitch +5.3° in the final sample. Log: `tmp/rs5-ui-60dps-check.jsonl`. No automatic full-speed or full-turn movement was performed.

### Automatic input and connection reliability update

Removed the Enable/Stop buttons and mouse/PS4 selector. Fresh held input selects the device automatically, and release stops and relinquishes control. L1 remains mandatory for controller movement. The existing 60°/s cap, analog response, and absence of added travel limits remain. Tests cover held-at-connect, controller replacement, competing devices, focus loss, fault recovery, and release acknowledgements; no still-held gesture can restart after a fault.

The new CAN arbitration policy and persistent fault telemetry were flashed and hash-verified. A normal USB output-drain interval was also fixed after the first hardware connection attempt exposed a startup race. Twenty Python unit/integration tests, Node mapping/router tests, a test of the actual frontend with DOM/event fixtures, JavaScript syntax checks, and the sanitized test of actual firmware transport logic passed.

A **90-second read-only hardware check received 900 validated joint replies**, with zero bus errors, TX failures, receive drops, overruns, REC or TEC. It stayed disarmed with zero requested speeds and disconnected afterward. No arbitration-loss events occurred during that check, so the original intermittent fault cause remains an inference supported by the single-shot configuration and Espressif's documented behavior. The bounded retry/deadline paths were exercised in the fake-TWAI test. Log: `tmp/rs5-ui-can-retry-soak.jsonl`. Actual mouse/PS4 motion and full-speed rotation remain for the operator; no automatic motion was used for this check.

### Combined UWB update — 2026-09-29

UWB follow is integrated into the same UI, bridge, and Feather firmware as mouse/PS4 control. In the wired build, factory Makerfabs UART input goes to RX/GPIO38; CAN wiring stays GPIO5/6. X toggles follow with a fresh tag, while manual input cancels it. The UI includes tag selection, live range/bearing, separate direction/center/speed settings, and an expandable connection layout. See [UWB setup and validation](UWB_SETUP.md). The combined wired build was flashed and hash-verified on 2026-09-29. On 2026-10-04 the user confirmed successful wired tracking through the anchor, ESP32, Waveshare and Mill-Max harness. The newer two-ESP32 wireless connection is implemented and software-tested; physical wireless following remains to be checked.

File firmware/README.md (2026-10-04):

# RS5 firmware

**For the camera-to-RS5 wireless setup, flash both ESP32s using the [main README's complete flashing and pairing steps](../README.md#flash-both-esp32s).** Both boards are Adafruit Feather ESP32-S3, 8 MB / No PSRAM, using Arduino-ESP32 3.3.11.

| Use | Firmware |
| --- | --- |
| Camera ESP32: anchor UART → ESP-NOW | [rs5_anchor_radio](rs5_anchor_radio/README.md) |
| RS5-body ESP32: ESP-NOW → tracking → Waveshare CAN → Mill-Max harness | [rs5_wireless_control](rs5_wireless_control/README.md) |
| Original wired UART → CAN setup, with Control Desk | [rs5_manual_control](rs5_manual_control/README.md) |
| Passive CAN diagnostics | `rs5_can_monitor`, documented below |

The user confirmed the Mill-Max interface and successful tag following through the direct wired path on 2026-10-04. The wireless firmware is implemented and software-tested; physical pairing and wireless following still need validation. The anchor and tag retain their factory firmware. See [wireless wiring/power](WIRELESS_UWB.md) and [Control Desk setup](../control_ui/UWB_SETUP.md).

## RS5 CAN monitor for Adafruit Feather ESP32-S3

Open [rs5_can_monitor/rs5_can_monitor.ino](rs5_can_monitor/rs5_can_monitor.ino) in Arduino IDE. The target is the **Adafruit ESP32-S3 Feather with STEMMA QT / Qwiic, 8 MB flash, no PSRAM (product 5323)**, using its built-in TWAI controller and the Waveshare SN65HVD230 transceiver. No additional Arduino libraries are required.

For Makerfabs STM32 AoA tracking through the existing UI and PS4 X button, use the [combined manual + UWB sketch](rs5_manual_control/README.md) and [connection/setup guide](../control_ui/UWB_SETUP.md). The separate [console UWB prototype](rs5_uwb_tracker/README.md) is also retained. It keeps CAN on GPIO5/6 and adds anchor UART input on RX/GPIO38. This page describes the standalone passive CAN monitor.

The firmware listens at **1,000,000 bit/s, Classical CAN**. It accepts all IDs and prints a sample of received frames, with separate counters for standard data frames on the inherited DJI IDs `0x222` and `0x223`. The bitrate worked in the 2026-09-28 RS5 passive receive test, which showed ID `0x426`. Subsequent tests with the separate [motion bench sketch](rs5_can_motion_test/README.md#hardware-result--2026-09-28) verified SDK joint queries on 0x223, replies on 0x222, and three small yaw cycles; this passive sketch never sends commands.

For the next diagnostic after successful passive reception, the separate [CAN acknowledgment monitor](rs5_can_ack_monitor/README.md) runs in normal CAN mode with automatic ACK/error signaling but no application messages or DJI commands. This original sketch remains permanently listen-only.

After successful SDK joint-angle queries, the separate [finite motion bench test](rs5_can_motion_test/README.md) provides three supervised small pan cycles with telemetry, heartbeat, and angle bounds. It needs no UWB kit and never starts movement automatically.

For interactive mouse or PS4 control, use the [Control Desk UI](../control_ui/README.md) with the [manual-control sketch](rs5_manual_control/README.md). It controls pan and tilt up to 60°/s without added software travel limits, leaves roll fixed, and requires a fresh held mouse/L1 gesture plus live input and telemetry.

**This version always uses listen-only mode.** It sends no CAN messages, acknowledgments, or error frames, has no transmit command, and never switches to an active mode. A quiet bus is inconclusive: an RS5 may wait for a query, and a solitary transmitter cannot get an acknowledgment from this listener. The firmware cannot discover ground or protect against connecting a supply pad to CANH/CANL.

## Wiring

Use the Feather header pads labelled **5** and **6**: they are GPIO5 and GPIO6. These are not physical header positions or the pads labelled TX/RX. GPIO4 is SCL on this Feather and is shared with the onboard I2C devices and STEMMA QT; this sketch leaves it alone. The two CAN pin constants are at the top of the sketch.

| Feather header label | Waveshare board |
| --- | --- |
| 5 (GPIO5) | CAN TX |
| 6 (GPIO6) | CAN RX |
| 3V (regulated 3.3 V) | 3.3V |
| GND | GND |

TX connects to TX and RX to RX on this board: CAN TX is the transceiver's input from the controller, and CAN RX is its output to the controller. They are not UART signals.

After verifying the RS5 contacts:

| RS5 signal | Connection |
| --- | --- |
| CAN-H | Waveshare CANH |
| CAN-L | Waveshare CANL |
| Verified GND | Common Waveshare/ESP32 GND, even though the Waveshare GND pin is on the other side |
| Both VCC contacts | Individually insulated, unconnected |
| SBUS_RX | Insulated, unconnected |
| AD_COM | The project's 47 kOhm pull-down, only after identifying this contact; never a direct short |

Use USB to power the Feather and its **3V** output to power the Waveshare. The RS5 accessory output must not connect to this supply. Twist CANH/CANL together. Fit or remove the gimbal adapter with all power disconnected. See the [main electrical checks](../README.md#termination-and-first-electrical-checks) for ground, pad orientation, and bus termination.

Check the unpowered, disconnected Waveshare's resistance between CANH/CANL before adding a resistor: it may already have termination. Account for that resistance when checking the complete bus. The older SDK ties accessory detection to port power; whether AD_COM is required for RS5 CAN alone remains unverified.

The sketch holds GPIO5 HIGH (recessive) from the beginning of setup. An optional 10 kOhm pull-up from Waveshare CAN TX to its 3.3V keeps that input high while the ESP32 GPIO is floating during reset. This does not replace pinout verification.

## Flash with Arduino IDE

1. Install **esp32 by Espressif Systems**, version **3.3.11** (the build used here), through Boards Manager.
2. Open the sketch and select **Adafruit Feather ESP32-S3 No PSRAM**. Keep **Flash Size: 8MB**, **Flash Mode: QIO 80MHz**, and **Partition Scheme: TinyUF2 8MB (2MB APP/3.7MB FATFS)**. This profile already disables PSRAM.
3. Use the Feather's USB-C connector. Keep **USB Mode: USB-OTG (TinyUSB)**, **USB CDC On Boot: Enabled**, and **Upload Mode: USB-OTG CDC (TinyUSB)**, the defaults for this board.
4. Select the connected port and upload with the RS5 disconnected. If the board does not enter download mode automatically, hold BOOT, tap RESET, release BOOT, then select the new port and upload. Reset after the first upload if needed.
5. Open Serial Monitor at **115200 baud**. If the startup banner has already passed, send `h`; status repeats once per second.

The Feather uses native USB for serial output. Its header TX/RX pins are unused by this sketch. Uploading installs this Arduino application in place of any existing application such as CircuitPython; copy any files you need from CIRCUITPY first.

## Flash with Arduino CLI

Run these from the repository root. The board profile selects 8 MB flash, no PSRAM, TinyUSB serial, and the TinyUF2 partition layout.

```sh
arduino-cli compile \
  --fqbn esp32:esp32:adafruit_feather_esp32s3_nopsram \
  --warnings all \
  --build-path "$PWD/tmp/firmware-build-feather" \
  --output-dir "$PWD/tmp/firmware-feather" \
  firmware/rs5_can_monitor

arduino-cli board list
```

Replace `YOUR_PORT` below with the actual port, such as `/dev/cu.usbmodem...` on macOS or `COM5` on Windows. Close any existing serial monitor before uploading.

```sh
arduino-cli upload \
  --fqbn esp32:esp32:adafruit_feather_esp32s3_nopsram \
  --port YOUR_PORT \
  --input-dir "$PWD/tmp/firmware-feather" \
  firmware/rs5_can_monitor

arduino-cli monitor --port YOUR_PORT --config baudrate=115200
```

Native USB can re-enumerate after flashing; check `board list` again if the port changes. A first upload from the ROM bootloader may require an explicit `--board-options UploadMode=default` on the upload command to skip the TinyUSB 1200-baud reset sequence; the sketch still uses TinyUSB serial after it starts.

## First test and output

Start with the Feather and Waveshare connected to each other and **CANH/CANL disconnected from the RS5**. With USB and any LiPo battery disconnected, check the Waveshare's CANH-to-CANL resistance and record it. Then power the Feather by USB and use DC-voltage mode (black lead in COM, red in V/ohms) to check approximately **3.3 V between Waveshare 3.3V and GND**. Keep the probe tips from bridging adjacent pins; resistance/continuity mode is only for unpowered checks.

Seeing `LISTEN_ONLY RUNNING` and repeating status proves the firmware/USB/TWAI driver started. `rx=0` is expected. This does not test the transceiver's CAN path or confirm the gimbal contacts.

After confirming the gimbal wiring and termination, turn all power off, connect the RS5 CANH/CANL and common ground, then power the ESP32 and RS5. Keep the gimbal's motion area clear for its own startup. Open the serial monitor and observe.

An illustrative frame line (the payload below is only an example):

```text
[4200 ms] STD ID=0x222 DATA DLC=8 01 02 03 04 05 06 07 08
```

The timestamp is time since ESP32 boot when the application reads the frame, not a bus capture timestamp. `STD` means an 11-bit ID, `EXT` a 29-bit ID, and `RTR` a remote request with no payload. The monitor does not reassemble DJI packets or validate their SDK CRCs.

| Output | Meaning |
| --- | --- |
| `rx` | Total frames read from the TWAI receive queue since boot |
| `id222`, `id223` | Standard data frames matching the inherited DJI IDs; ID matching alone does not validate an SDK reply |
| `bus_errors` | Driver's cumulative bus-error count; inspect bitrate, termination, continuity, and wiring if it increases |
| `rx_missed`, `fifo_overrun` | Driver-reported receive losses; this is not a lossless bus recorder |
| `REC`, `TEC` | Driver error counters; zero in listen-only mode does not prove electrical correctness |
| `queued` | Frames currently waiting in the driver's receive queue |
| `alerts` | OR of driver alert flags since the previous status report |
| `omitted` | Frame previews omitted by the 20-per-second limit or by pausing previews; these frames still count toward `rx` |
| `console_skipped` | Whole output lines skipped because serial was unavailable or the 4 KB console queue was full; queued lines drain in USB-sized chunks |

Send `h` or `?` for help, `s` for immediate status, and `p` to toggle frame previews. Any serial line ending works. These commands only change local output. Reception continues without an open serial monitor.

Valid frames are evidence that the receive path and bitrate work. Repeated frames may be retries caused by missing acknowledgments. **No frames does not mean the wiring is wrong, and zero errors does not mean it is right.** After confirming the wiring, the separate [tracker's optional query mode](rs5_uwb_tracker/README.md#optional-motion-build-after-electrical-and-preview-checks) is available as the next step if passive listening stays quiet; this monitor remains permanently passive.

## Validation

Compiled for `esp32:esp32:adafruit_feather_esp32s3_nopsram` with Arduino-ESP32 **3.3.11**: 359,366 bytes of application flash and 58,688 bytes of static RAM. On 2026-09-28 it was flashed and verified running on the Feather. The user's connected RS5 test received repeated standard ID `0x426` frames, including a 15-second interval with 115,383 received frames, no additional bus errors, and no reported receive losses. These results validate passive reception in that setup, not SDK query/control compatibility. See the separate [acknowledgment diagnostic results](rs5_can_ack_monitor/README.md#hardware-validation--2026-09-28) for the follow-up test.

That core emits a command-line macro warning for its default hyphenated partition name (`ARDUINO_PARTITION_tinyuf2-partitions-8MB`). The build succeeds; the sketch does not use that macro.

The console queue test passes with address/undefined-behavior sanitizers, covering TinyUSB's 64-byte output chunks, wraparound, partial writes, a stalled sink, and whole-line rejection on overflow. To repeat from the repository root after the firmware build has created `tmp/`:

```sh
c++ -std=c++11 -Wall -Wextra -Werror -fsanitize=address,undefined \
  firmware/tests/console_queue_test.cpp -o tmp/console_queue_test
./tmp/console_queue_test
```

## References

- [Adafruit Feather ESP32-S3 pin descriptions](https://learn.adafruit.com/adafruit-esp32-s3-feather/pinouts)
- [Adafruit Feather ESP32-S3 Arduino setup](https://learn.adafruit.com/adafruit-esp32-s3-feather/using-with-arduino-ide)
- [Espressif TWAI driver used by this sketch](https://docs.espressif.com/projects/esp-idf/en/v5.4/esp32s3/api-reference/peripherals/twai.html)
- [Arduino-ESP32 USB flashing and serial settings](https://docs.espressif.com/projects/arduino-esp32/en/latest/tutorials/cdc_dfu_flash.html)
- [Waveshare SN65HVD230 CAN Board](https://www.waveshare.com/product/sn65hvd230-can-board.htm)

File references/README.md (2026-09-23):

# Reference sources

Restored on 2026-09-23 using the sources cited in the project README. The PDFs,
community STL, and upstream README are unmodified source files. The PNGs are
page renders or crops, with white backgrounds for readability.

| Local file | Source |
| --- | --- |
| [dji-rs5-user-manual.pdf](dji-rs5-user-manual.pdf) | [DJI RS 5 User Manual, English](https://dl.djicdn.com/downloads/DJI_RS_5/20260115/UM_2/DJI_RS_5_User_Manual_en.pdf), 37 pages |
| [dji-rs5-overview.png](dji-rs5-overview.png) | RS5 manual, PDF/printed page 6 |
| [dji-rs5-ports.png](dji-rs5-ports.png) | RS5 manual, PDF/printed page 17 |
| [dji-r-sdk-v2.5.pdf](dji-r-sdk-v2.5.pdf) | `SDK documentation_20210729/DJI_R_SDK_Protocol_and_User_Interface_EN_v2.5.pdf` inside [DJI's SDK archive](https://terra-1-g.djicdn.com/851d20f7b9f64838a34cd02351370894/Ronin%E7%B3%BB%E5%88%97/SDK%20documentation_20210729.zip), linked by the [DJI RS SDK page](https://www.dji.com/rs-sdk); 22 pages |
| [dji-sdk-pinout.png](dji-sdk-pinout.png) | SDK PDF page 21 / printed page 19, section 3.1.2, including the illustration, signal table, and orientation note |
| [millmax-889-family.pdf](millmax-889-family.pdf) | [Mill-Max 889-22-014-70-501010 datasheet hosted by DigiKey](https://mm.digikey.com/Volume0/opasdata/d220001/medias/docus/6448/8892201470501010.pdf), 2 pages; page 1 contains the 889-22-0XX family drawing |
| [millmax-889-drawing-detail.png](millmax-889-drawing-detail.png) | Family drawing cropped from page 1 of the Mill-Max PDF |
| [rileyharmon-rs2-connector.stl](rileyharmon-rs2-connector.stl) | Riley Harmon's [3d-print-ronin-can-connector.stl](https://github.com/rileyharmon/DJI-Ronin-RS2-Log-and-Replay/blob/38b6f139398a4b34156e8ca66073ca1744ca357b/3d-print-ronin-can-connector.stl) |
| [rileyharmon-README.md](rileyharmon-README.md) | Riley Harmon's [original README](https://github.com/rileyharmon/DJI-Ronin-RS2-Log-and-Replay/blob/38b6f139398a4b34156e8ca66073ca1744ca357b/README.md), including attribution and CC BY-NC 4.0 license notice |

The Riley Harmon files were downloaded from `main`, whose head at restoration
was `38b6f139398a4b34156e8ca66073ca1744ca357b` (2022-12-06).
Credit to Riley Harmon, Cornelius von Einem, and Casey Basichis as stated in the
upstream README. DJI and Mill-Max documents retain their original notices.

The image restoration reused surviving renders in `tmp/pdfs/` after comparing
their associated PDF page text with the freshly downloaded PDFs and visually
checking the images. These temporary files are not needed to use the references.
For reproduction, all four source pages were rendered at three times their PDF
point dimensions (216 dpi). The SDK image retains pixels `(0, 0, 1174, 1090)` from its page render;
the Mill-Max detail retains `(100, 435, 1010, 1055)`. Crop coordinates are
`(left, top, right, bottom)` measured from the upper-left corner.

The SDK pinout is the legacy RS2 illustration. Restoring it does not independently
validate the RS5 electrical or mechanical assumptions documented in the project
README.

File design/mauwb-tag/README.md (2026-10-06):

# Pocket case for the Makerfabs STM32 AoA tag

Prototype rev D (M3 heat-set inserts and rocker opening) for the **original MaUWB STM32 AoA kit's TAG**, with its display and **no expansion header strips fitted**. The anchor has a different radio shape and does not fit this case.

User choices: smallest practical case, roughly **1–2 hours** of use, a **removable battery charged externally**, and no modification to the tag's PCB. The runtime target still needs a current measurement and a discharge test.

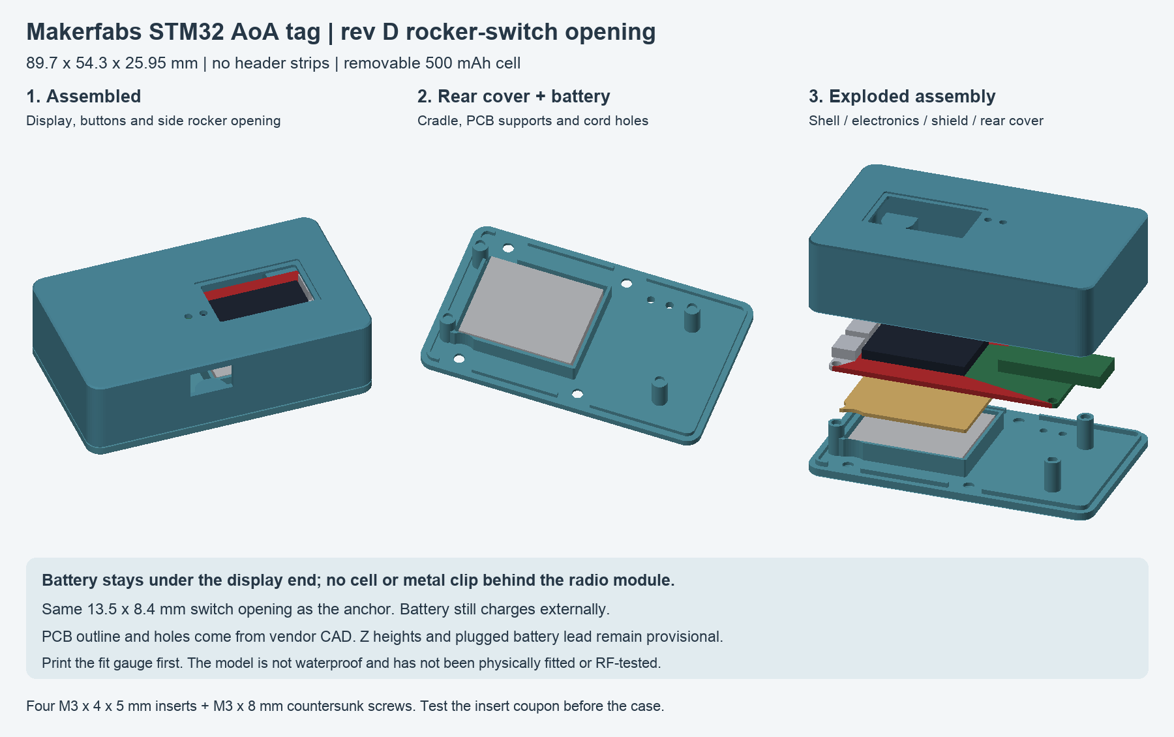
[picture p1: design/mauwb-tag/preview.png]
Case, battery tray and exploded assembly


## Proposed specification

| Item | Rev D specification |
| --- | --- |
| Outside dimensions | **89.7 × 54.3 × 25.95 mm**, including all three printed parts; height is provisional |
| Carrier PCB | 72 × 32.6 mm, with 1.5 mm corner radius, from vendor V1.1 CAD |
| Four PCB holes | Ø3 mm; 68 × 28.6 mm center spacing, 2 mm from nominal board edges |
| Tag radio allowance | Vendor footprint spans x=50–82 mm, including a 10 mm overhang beyond the carrier; confirm actual X3-MAX module |
| Battery | Protected **1S LiPo, 3.7 V nominal / 4.2 V full, 500 mAh** |
| Cell design envelope | **36 × 29 × 4.75 mm**, excluding the loose plug and lead |
| Battery space | 1 mm clearance on each side and 1 mm total vertical allowance, including any pad/pull tab |
| Construction | Rounded front shell, removable rear cover, separate 1.2 mm rigid battery shield |
| PCB retention | Four locating pegs and opposing corner supports; no screws through the PCB |
| Closure | Four **M3 × 8 mm countersunk screws**, 90° heads up to 6.72 mm, into four **JROUTH M3 × 4 × 5 mm heat-set inserts** |
| Insert pockets | **4.6 mm trial diameter × 5 mm deep** in 10 mm bosses; test the coupon before the case |
| Access | Recessed screen window and small recessed button holes; optional clear PET screen cover |
| Rocker switch opening | **13.5 × 8.4 mm**, exactly the same aperture as the camera anchor, on the BAT-connector long side |
| Charging | Battery removed and connected to an external charger; default case covers both tag USB ports |
| Carrying | Pocket-size body plus two holes for soft cord / attachment to a garment clip |
| Material | Plain, unfilled PETG suggested; no metal coating or carbon/metal-filled filament |
| Environmental rating | None: open button/cord holes and an optional glued screen film are not a weather seal |

This is about the size of a thick remote, suitable for checking against your actual pocket. It is not a tiny tracker module. The development board, display, radio overhang and mated battery plug determine the minimum size. After measuring the assembled tag, `top_clearance` may be reducible from the current conservative 10 mm.

## Files and first print

- [OpenSCAD source](enclosure.scad): all dimensions and clearances are editable; `part="print_plate"` is the default.
- [Fit gauge](fit-gauge.stl): print this first. It checks the nominal PCB footprint and four-hole pattern, not component height or battery fit.
- [Insert fit coupon](insert-coupon.stl): print before the enclosure; five labeled holes from 4.4 to 4.8 mm for your actual inserts and filament.
- [Switch fit coupon](switch-coupon.stl): exact 13.5 × 8.4 mm opening through the tag's 1.6 mm wall; check the rocker clips before printing the shell.
- [Front shell](front.stl), [rear cover](rear.stl), [battery shield](shield.stl).
- [Three-part print plate](print-plate.stl): already oriented on the print bed, in millimeters, at 100% scale.
- [Switch location and dimensions](switch-preview.png): assembled view and dimensioned view of the exported side wall.
- [Mesh checks](mesh-checks.json): closed meshes, dimensions and checks for volumetric interference against simplified reference geometry.
- [Vendor measurements](vendor-measurements.json): extracted XY data, provenance, and provisional values.

Print the board gauge, insert coupon and switch coupon first, then **either** the three-part print plate **or** the individual front, rear and shield files. The plate already contains those three case parts; it does not include the gauge or coupons. **Rev D changes only the front shell relative to rev C.** Reuse your rev C rear cover and battery shield; reprint [front.stl](front.stl) to add the opening. The PCB gauge and insert coupon are unchanged. Revisions before C use different closure geometry and should not be mixed with this set.

## Same rocker opening as the camera anchor

The front shell now has the anchor's exact **13.5 mm wide × 8.4 mm high rectangular aperture**, with no additional tolerance, rounded corners or chamfer. It fits the same measured **13.27 × 8.18 mm KCD11-101 style switch body** on the drawing, giving **0.23 × 0.22 mm total clearance**. See the [anchor switch reference](../mauwb-anchor/README.md#exact-rocker-opening-and-charging).

The hole is on the **BAT-connector long side (+Y)**, above the PCB and the closure boss near the buttons. Its center is **x=48 mm, z=19 mm** in assembly coordinates; its outside wall is **y=44.3 mm**. Width runs along the case length and height through its thickness. There is **2.75 mm of plastic to the outer top**. Overall case dimensions remain **89.7 × 54.3 × 25.95 mm**.

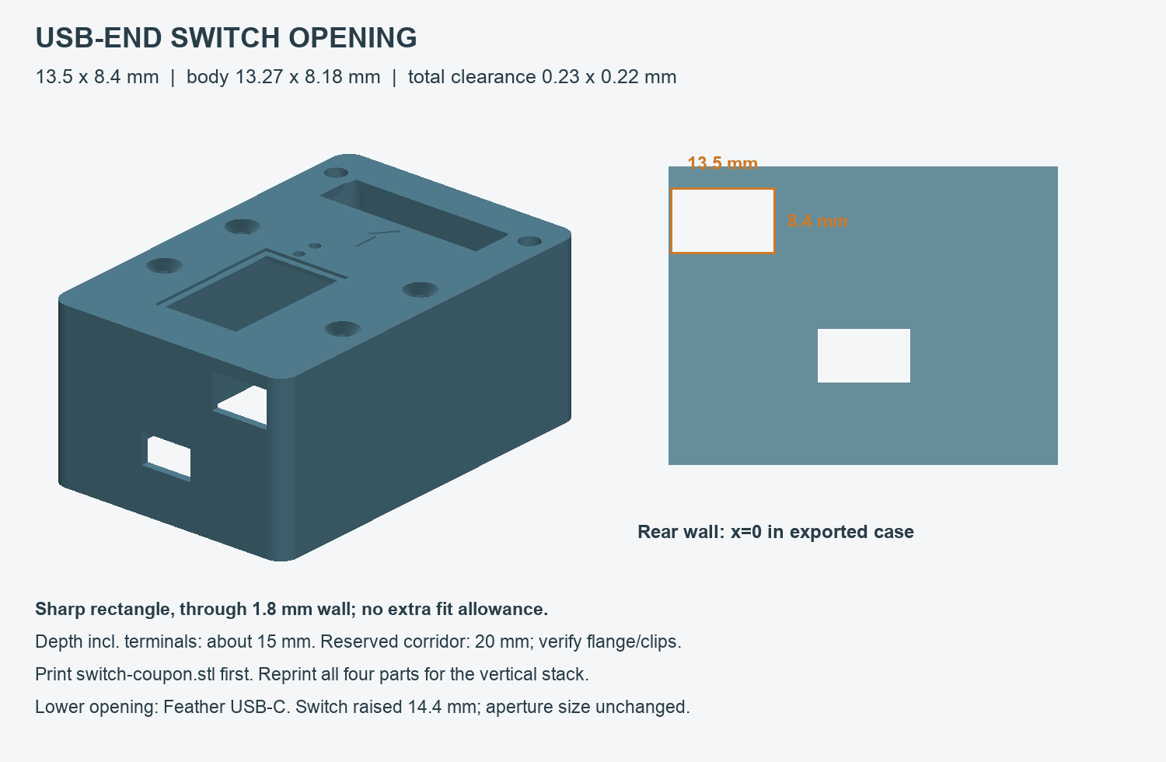
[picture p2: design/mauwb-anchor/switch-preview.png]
Tag rocker opening and dimensions


The switch's approximately **15 mm installed depth including terminals** gets a **20 mm reserved corridor** inward from the outer wall. The modeled body clears the top of the PCB by **0.56 mm**. That corridor clears the simplified screen and radio envelopes and the printed parts. Actual flange, clips, terminal spread, insulation and bent wires are not modeled; check them on the real assembly. Keep leads in the BAT-connector side lane, clear of the antenna and case joint.

The tag wall is **1.6 mm**, compared with the anchor's **1.8 mm**. Print the tag's [switch coupon](switch-coupon.stl), **23.5 × 18.4 × 1.6 mm**, to check both aperture fit and clip retention at this thickness. The same hole dimensions do not establish printed fit or clip grip. The opening can be disabled with `switch_opening=false` when regenerating a shell without a switch.

Use the rocker in a removable battery-extension harness, with the switch **in series with battery positive**, and keep battery negative continuous:

```text
Battery + ---- rocker ---- tag BAT positive
Battery - --------------- tag BAT ground
```

Verify connector polarity as described below, insulate both switch terminals, and assemble with the battery unplugged. Neither switch terminal connects to ground. With USB disconnected, open contacts turn the tag off. The battery still comes out for external charging; the switch does not change the stock charger's current or provide in-case charging. No tag PCB modification is required for this harness.

### M3 screw fit

The provided STLs use four **M3 × 8 mm countersunk screws** with a 90° head. The 7 mm countersink accommodates the [ISO 10642 M3 head's 6.72 mm maximum diameter](https://www.accu.co.uk/countersunk-socket-head-screws/5595-SSK-M3-6-A4). Measure your screws before printing: M3 describes the thread, not the length or head shape. Countersunk screw length includes the head; button/pan/socket screw length is measured under the head.

The rear cover is 2.8 mm thick, leaving 1 mm beneath the countersink. Clearance holes are 3.4 mm; front insert pockets are 4.6 mm in 10 mm bosses with webs to the sidewalls. The insert bosses move outward, adding 2.6 mm to rev B's case width while retaining its height. The battery has at least 1.3 mm nominal clearance from the nearest boss envelope. These screws close the case and do not pass through the PCB.

For **M3 × 8 mm button, pan or socket-head screws**, set `case_screw_seat="flat"` and re-export the rear cover or print plate. This removes the countersinks, providing a flat bearing surface. Such heads stand proud of the rear surface and add their height to the carrying envelope. Do not seat a flat-bottomed head directly in the supplied countersink. A different screw length requires checking engagement and blind-hole depth before assembly; do not simply substitute longer screws.

### JROUTH heat-set inserts and first fit

Use the **M3 × 4 × 5 mm** inserts: M3 internal thread, **4 mm body length**, and 5 mm nominal outside diameter, measured by the user as **4.99 mm**. The longer 6, 8 and 10 mm inserts are not used in this revision. Four inserts are needed for the case, plus spares for the coupon. **The supplied STLs now have insert pockets; screws cannot fasten directly into those larger holes.**

No manufacturer-specified receiving-hole diameter was found for this exact JROUTH insert. **4.6 mm is a proposed starting fit, not a verified supplier dimension.** Do not make the receiving hole 4.99 mm just because that is the insert OD: softened plastic must engage the knurling. The model assumes straight, unheaded heat-set inserts.

The separate **62 × 23 × 9.6 mm** coupon has five labeled modeled diameters: **4.4, 4.5, 4.6, 4.7 and 4.8 mm**. It uses the same 10 mm boss diameter, 5 mm insert-pocket depth, screw-tip relief and vertical hole orientation as the case. Print it at 100% scale with the same material, layer height, walls and slicer hole compensation planned for the case. Labels give CAD diameters; printed diameters may differ.

Start with the **4.6** hole and a spare 4 mm-long insert. Heat-install it squarely with controlled heat and light pressure, flush with the boss surface, then let it cool completely. It should stay fixed when you gently thread a screw in, without cracked/bulged plastic or blocked threads. Do not force a cold insert into the hole. If seating requires excessive pressure or distorts the boss, try a larger coupon hole; if the cooled insert is loose or spins, try a smaller one. Stop screw insertion before bottoming out; the coupon has no rear cover to establish the final screw seating position. A trial fit does not establish a rated pull-out strength.

If a diameter other than 4.6 works best, change **`insert_hole_diameter`** to that value and regenerate the STLs before printing the enclosure. Do not scale the whole model. Keep `use_heat_set_inserts=true`, `insert_outer_diameter=4.99` and `insert_length=4` for the selected hardware.

Pockets have 1 mm extra depth below the 4 mm insert, plus a narrower 3.4 mm screw-tip relief reaching about 7.3 mm from the boss mouth. An M3 × 8 mm countersunk screw passes through the 2.8 mm cover, engages the full insert and ends in that relief. Do not substitute a longer screw without checking the blind depth. The insert installs flush at the boss mouth from the open rear of the empty front shell.

The geometry guard requires boss diameter at least twice the insert OD and at least 0.7 mm of material at the blind end. These choices follow [SPIROL's guidance on hole sizing, boss diameter and extra depth](https://www.spirol.com/resources/white-papers/how-to-design-the-proper-hole-for-heat-ultrasonic-inserts/); they do not replace the actual insert supplier's specifications or the coupon test. Heat-install inserts only with the electronics and battery removed, then allow them to cool before trial assembly. The source retains `use_heat_set_inserts=false` for a separately regenerated direct-thread version; the delivered meshes use inserts.

The model is **not physically fitted or RF-tested**. Before printing the full case, check these on your unpowered tag:

1. The red carrier is approximately **72 × 32.6 mm**, and its four holes line up with the gauge. Hold the gauge loosely; do not press components onto it or force a peg through a hole.
2. Measure from the USB-end **PCB edge** to the far end of the tag antenna. The case currently reserves an overall radio/board extent of **82 mm** along that direction; the USB metal mouth projects about 0.7 mm in the opposite direction in the source footprint.
3. Measure the highest part **above the top PCB surface**, including the fully inserted battery plug and a relaxed wire bend. It must fit within the current **10 mm** top clearance. Also check the tallest underside component against the **3 mm** underside space. The board itself is provisionally 1.6 mm thick.
4. Confirm the screen and button positions. Those XY locations come from the vendor footprint, but the window size, glass thickness, component heights and connector bend allowance are provisional.

The V1.1 layout is a source reference, not a measurement of your delivered board. Product photos show V1.0 hardware too. Adjust the source if your revision differs. Do not scale the entire STL to make one feature fit: this would also change the hole spacing and battery compartment.

## Battery and charger selection

The concrete size reference is **[Adafruit 1578, 500 mAh protected LiPo](https://www.adafruit.com/product/1578)**, specified as 29 × 36 × 4.75 mm with a two-pin JST-PH lead. Its supplier limits charging to **500 mA or less**. The 102 mm lead must be folded gently into the connector-side space, away from the antenna and outside the shell joint; it is not included in the cell's stated dimensions.

Use **[Adafruit 4410 USB-C Micro-Lipo charger](https://www.adafruit.com/product/4410)** externally, initially at its factory **100 mA** setting. It is intended for the matching Adafruit 3.7/4.2 V batteries. A 500 mAh cell takes roughly five hours plus charge taper from empty at that setting; use the charger's completion indication. The charger stays outside the wearable case.

The Makerfabs V1.1 schematic shows **TP4056 U6 and a 1.2 kΩ R27**, corresponding to approximately **1 A programmed charge current** in the [charger manufacturer's datasheet](https://www.toppwr.com/uploadfile/file/20240130/65b892bb04a3c.pdf). That exceeds the proposed cell's charging limit. The stock charger is not a discharge-protection circuit, which is why the specified cell has its own protection.

**Do not connect either tag USB port with this battery attached to an unmodified tag.** This design intentionally leaves the USB openings closed. For USB programming or bench testing, remove the battery, then remove the board from the case. A future board modification could reduce R27's programmed current, but no such modification is assumed here. The source exposes `usb_openings=true` for an appropriately modified or battery-free configuration; it is not enabled in the provided STLs.

### Connector and polarity

The board footprint is **PH 2.0 mm, two pins**. The schematic connects **BAT pad 1 to VBAT positive and pad 2 to GND**. In the source coordinates, pad 1 is at `(9.001, 30.75)` and pad 2 at `(7.001, 30.75)`. These coordinates do not mean “left” or “right” when looking at the loose battery plug.

Before the first connection, with USB and battery removed, identify the socket's GND contact by continuity to a labelled board GND. Separately check the battery plug's voltage/polarity with your meter in DC-voltage mode, using insulated probe tips that cannot bridge the adjacent contacts. A mating connector shape alone does not guarantee matching polarity. If the pack and tag disagree, use a correctly wired adapter on the **tag side**. The battery should still connect directly to its matching external charger. Never force the plug or infer polarity solely from wire color.

### Runtime target

For budgeting only, `hours ≈ usable capacity in mAh / average battery current in mA`. Using an illustrative 80% usable fraction of a 500 mAh pack:

| Measured average current | Budgeted runtime |
| --- | --- |
| 100 mA | About 4 hours |
| 200 mA | About 2 hours |
| 300 mA | About 1.3 hours |
| 400 mA | About 1 hour |

These are calculations, not measured currents for this tag or guaranteed runtimes. The display, ranging firmware, transmit settings, regulator dropout and cell behavior affect the result. Confirm the chosen cell's discharge rating against measured steady and peak loads; a basic multimeter only gives a rough average and may miss peaks. An actual ranging-session discharge test is the final check.

If measuring current with your multimeter, use a suitable connector breakout and insert the meter **in series** with one battery lead, with the correct fused current input/range and USB disconnected. Never place a meter in current mode directly across the battery or socket. Return its lead to the voltage jack afterward. This measurement does not require soldering headers onto the tag.

## Pocket behavior

A plastic enclosure and ordinary clothing are plausible starting points, but **pocket carry is not guaranteed to retain a usable bearing as you turn**. Human-body shadowing can cause attenuation, reflected-path measurements and large ranging errors; the effect changes with body orientation. This is documented in [body-shadowing research](https://pmc.ncbi.nlm.nih.gov/articles/PMC10575093/), although it does not measure this particular Makerfabs case.

Start with the antenna end at the top of a loose front or chest pocket, facing outward toward the camera, separated from your phone, keys, coins and belt hardware. Keep the case in a consistent orientation. If bearing becomes unstable during turns, move it to an outside garment clip or strap with the antenna unobstructed. A single tag can still be shadowed when your body is between it and the camera; no case shape removes that limitation.

The battery ends at x=41.5 mm; the model's radio envelope starts at x=50 mm, leaving **8.5 mm of longitudinal separation** and no battery directly behind that module. This is a layout choice, **not an RF-certified keep-out distance**. Keep excess battery lead and any metal clip away from the radio/antenna end. The plain plastic wall can also affect tuning; compare the bare and enclosed tag before relying on it.

Test with the gimbal disarmed: establish a stationary reference at 2–3 m, then compare the bare tag, enclosed tag, pocket position and outside attachment. Rotate through the body orientations you expect to use, recording angle jitter, bias and dropouts. Use the most reliable placement before adjusting tracking filters.

## Printing and assembly

Start with a 0.4 mm nozzle, 0.2 mm layers, and four perimeters in plain PETG. PLA is suitable for the fit gauge and a first fit trial. The provided orientations aim to avoid supports; inspect your slicer's preview, especially the locating pins and thin shield. Print the 1.2 mm shield solid. Do not sand or drill the case with the electronics or battery inside it.

1. Check the board gauge, insert coupon and switch coupon, then dry-fit the empty shell and cover. Heat-install four M3 × 4 × 5 mm inserts flush in the front shell, with the rear opening facing upward. Let them cool and clear any debris before installing electronics. Lightly trial-fit the four M3 × 8 mm countersunk screws with the empty rear cover in place. Confirm the screw ends cannot bottom out or protrude into the electronics space; do not substitute longer screws. Install the rocker and its insulated extension harness with the cell unplugged, checking its clips, flange and terminal clearance.
2. Place the front shell **screen side down** on a soft, clean surface. Install the tag component side toward the screen window, locating the PCB on the four pegs. Its corner pads support the PCB; the radio module and screen must remain free of pressure. Do not fit the loose expansion headers.
3. Fit a clear PET sheet if desired: approximately **32.8 × 20.3 × 0.5 mm** for the default recess, with thin perimeter adhesive. Verify actual printed recess dimensions first. Without this sheet the OLED window is open; the case does not protect the glass from objects entering it.
4. Put the protected cell in the rear cover's cradle with a thin nonconductive protective pad or pull tab if needed. The total available vertical allowance is only 1 mm; allow at least some free space and never tighten the case to compress a pouch cell. The cell's protected/lead end faces the wire-exit notch near the board's BAT connector.
5. Lay the separate rigid shield on the cradle rim over the battery. Its notches clear the locator columns, closure bosses and battery lead. The shield keeps solder joints away from the cell; it must not rest directly on or press the pouch.
6. Route the lead through the notch and up the connector-side lane to the switched extension harness. Keep the rocker OFF; plug into BAT only after checking polarity. Fold spare lead gently in that lane, clear of screws, PCB supports, lid joints and the radio module. Leave enough slack to open the rear cover and unplug the battery. Wire fit is a physical check: the reference CAD does not model every bend of the cable and added switch harness.
7. Close the rear cover and lightly tighten the four screws. It should seat without force. Confirm the board is captured at its corners and that nothing rattles enough to strain the lead. Any resistance requires inspection, not more screw torque.

Use the rocker to switch battery power off. For removal or charging, switch OFF, lay the case screen-down before opening it, lift the rear cover only enough to reach the connector, and disconnect the battery from the extension harness by its plug housing rather than pulling its wires. The battery-side switch terminal remains live while the cell is connected. The rear cover also retains the PCB, so support the board while open. Lift the shield and remove the cell, then charge it outside the case and outside your pocket, on a suitable nonflammable surface while attended. A damaged, swollen or hot cell must not be forced back into the enclosure.

## Regenerate and inspect

Open `enclosure.scad` and select `assembly` or `exploded` to inspect the layout. Reference electronics and the orange switch-clearance corridor are simplified boxes and are excluded from the printable parts. Set `part` to `front`, `rear`, `shield`, `fit_gauge`, `insert_coupon`, `switch_coupon` or `print_plate` before exporting an STL.

From the repository root:

```sh
python3 tools/build_tag_enclosure.py
```

The script uses OpenSCAD, NumPy and Pillow, exports seven printable meshes, checks connected/watertight geometry, and checks for positive-volume intersections with the nominal reference envelopes, including the reserved switch corridor. It probes both faces of the exported aperture and coupon at their corners and ±0.01 mm around each edge, and checks the dimensions against the anchor source. It produces `preview.png`, `switch-preview.png` and `mesh-checks.json`. It accepts `--openscad /path/to/openscad`. The default exports have been checked with **OpenSCAD 2015.03-3**. Intentional touching faces may appear in its collision-only exports with a non-manifold warning; those diagnostic surfaces are not printable parts.

Source coordinates use the vendor's top/component-side board view: x runs from USB toward the radio, y toward the BAT connector, and z toward the display. Model assembly origin z=0 is the back of the rear cover. The source's `top_clearance`, `bottom_component_height`, `bottom_clearance`, `radio_*`, battery dimensions and screen/USB access dimensions remain independently adjustable.

## Provenance

- [Makerfabs hardware repository](https://github.com/Makerfabs/UWB-AOA-with-Display-STM32F103C8T6/tree/34b9705edcb7feca83f652280047847d4bc03c34/Hardware): V1.1 Eagle board and schematic, used for carrier outline, hole coordinates, connector/screen placement and battery circuit. The U2 library footprint is named `UWB-X1-MAK-CA`; it is treated as a provisional envelope for the kit's published X3-MAX tag, not an exact 3D component model.
- [Makerfabs original kit](https://www.makerfabs.com/mauwb-stm32-aoa-development-kit.html): identifies the STM32 kit, tag/anchor roles and manufacturer product photos. Photos confirm that the tag module lies along the carrier and extends beyond its end; the anchor module stands differently.
- Battery and charger data above are from their linked manufacturer listings, checked 2026-09-26. A substitute battery requires a new dimension, polarity, charge-current and discharge-rating check.

All new enclosure geometry is constructed here from measured/source dimensions. The unrelated RS5 connector CAD and firmware remain separate.

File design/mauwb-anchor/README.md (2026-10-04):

# Camera-top STM32 anchor + Feather enclosure — prototype G

The camera unit now has a **mounted Adafruit Feather ESP32-S3 below the STM32 anchor and its upright antenna**. From bottom to top: the single 3.7 V / 500 mAh battery, insulating shield, Feather, then STM32. Direct soldered wires connect the boards internally; no cable crosses a moving gimbal axis. The stationary Feather/CAN unit remains on the RS5 body.

The footprint remains **87.7 × 58 mm**. The main body is **41.1 mm high**, and total height including the antenna hood is **72.81 mm**. The two cage holes remain **26.48 mm apart**. These are CAD dimensions; physical fit and enclosed radio performance have not been validated.

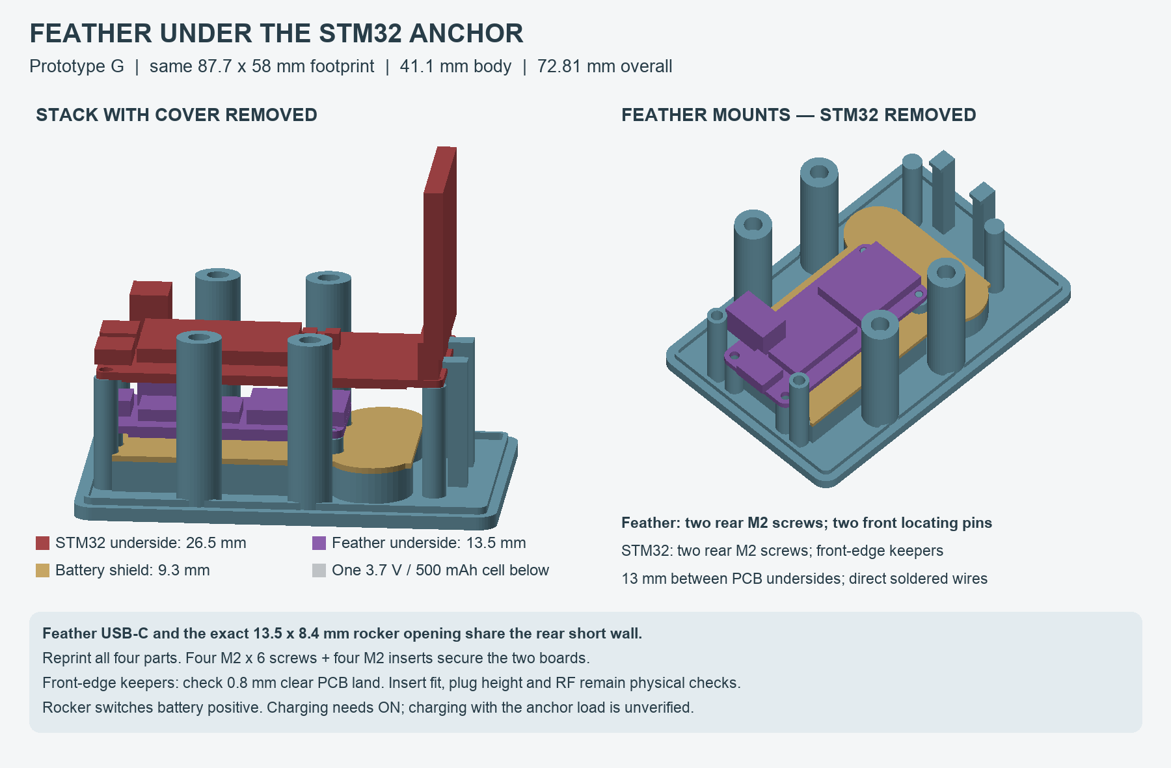
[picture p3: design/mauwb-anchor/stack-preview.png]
Stack and Feather mounting


## Board mounts and access

The **Feather uses two M2 × 6 mm screws at its USB end**, engaging heat-set inserts in the base, plus two front supports with **1.8 mm locating pins**. Adafruit's board CAD specifies 2.5 mm rear mounting holes and 2.2 mm front holes. The front pins avoid putting screw heads beside the ESP32 module/antenna. All four supports carry the PCB; the two rear screws retain it. Use a bare Feather with **no tall pin headers**, as confirmed by the user.

The **STM32 uses two M2 × 6 mm screws at its USB end and two front-edge keepers** built into the base. The keepers overlap the front PCB edge by **0.8 mm**, with **0.2 mm vertical clearance**, and remain below the upright antenna. The two front mounting holes rest on plain supports. No screws or lid pillars occupy those covered holes. To remove the STM32, unplug the relevant leads, remove its two rear screws, slide the board **1.5 mm toward USB**, then lift it with its antenna attached. Check that the delivered PCB has clear land at x=71.2…72 mm, y=8…12 and 22…26 mm; the modeled header ends at x=71 mm and remains provisional.

The Feather underside is at **z=13.5 mm** and the STM32 underside at **z=26.5 mm**: **13 mm between boards**. The provisional 8 mm-high mated Feather battery plug clears the modeled STM32 underside components by **1.4 mm**. Feather solder joints have **1 mm clearance above the shield**. These clearances assume short direct wires, no header sockets, 1.6 mm PCBs and the documented component envelopes.

A separate **12 × 7 mm USB-C access opening** exposes the Feather charger in the rear short wall. The connector face is approximately **2.56 mm behind the outer wall**, based on the vendor footprint. The opening is a trial cable-body allowance; check the actual plug and connector height. Both stock STM32 USB ports stay covered.

## Exact rocker opening and charging

The same rear short wall has the requested **13.5 mm wide × 8.4 mm high rectangular opening** for the measured **13.27 × 8.18 mm KCD11-101 style switch body**. Total clearance is exactly **0.23 × 0.22 mm**. There is **no added fit allowance, corner radius or chamfer**. The wall is x=0 in the exported case and x=-3.7 mm in the source assembly.

Its center is now **y=-2 mm, z=34.1 mm**. Raising it **14.4 mm from revision F** clears the higher STM32 and its screw heads, including vertical lid removal. The approximately **15 mm installed depth**, including terminals, has a **20 mm reserved corridor** with the measured body cross section. This corridor does not enlarge the opening. Flange, clips, terminal spread and bent leads remain unmeasured. The plastic above the opening is **2.8 mm** to the outer roof.

Print [switch-coupon.stl](switch-coupon.stl) to check the exact aperture in a 1.8 mm wall. The lower opening visible in the preview is for the Feather USB-C charger.

Rear switch and USB openings

The rocker now sits **in the battery's positive lead, before the camera Feather's JST**. Feather BAT/GND then feeds the STM32 battery socket. Leave Feather EN externally unconnected. **Closed contacts = ON; open contacts = battery OFF.** No electronic load-switch board is required. See the [power circuit and servicing instructions](../../firmware/WIRELESS_UWB.md#camera-side-power-direct-battery-switch).

**Charging through Feather USB-C requires the rocker ON.** The STM32 remains a load on BAT, so net charging current and proper charge termination still require measurement. OFF disconnects the cell from charging but does not isolate USB power. For an initial unloaded charging check, disconnect the anchor BAT pigtail and UART as described in the power guide. Keep the anchor USB ports disconnected. Unplug USB and the battery before internal service.

The same 13.5 × 8.4 mm switch opening, 20 mm reserved corridor and board mounts apply. Check the actual battery-current harness, terminal insulation and lead slack against the case; flexible wires are not represented by the component-envelope checks.

## Files

- [Editable OpenSCAD model](enclosure.scad): assembly by default; `part="exploded"` separates the layers.
- [Complete four-part print plate](print-plate.stl): **91.2 × 190 mm**, units mm, scale 100%.
- [Base](base.stl), [cover](cover.stl), [hood](hood.stl), [shield](shield.stl). **Reprint all four for revision G**; the hood height changes with the taller roof.
- [M2 board-insert coupon](board-insert-coupon.stl): 2.8 / 2.9 / 3.0 / 3.1 / 3.2 mm trial bores, ordered along the 48 mm length.
- [M3 insert coupon](insert-coupon.stl): 4.4 / 4.5 / 4.6 / 4.7 / 4.8 mm bores along the 65 mm length.
- [Switch fit coupon](switch-coupon.stl), [STM32 outline/hole gauge](fit-gauge.stl), [cage mounting gauge](mount-gauge.stl). Gauges/coupons are separate from the plate.
- [Measurements and provenance](measurements.json), [mesh/interference report](mesh-checks.json), [assembly preview](preview.png).
- [Build/check script](../../tools/build_anchor_enclosure.py): run `python3 tools/build_anchor_enclosure.py` from the repository root.

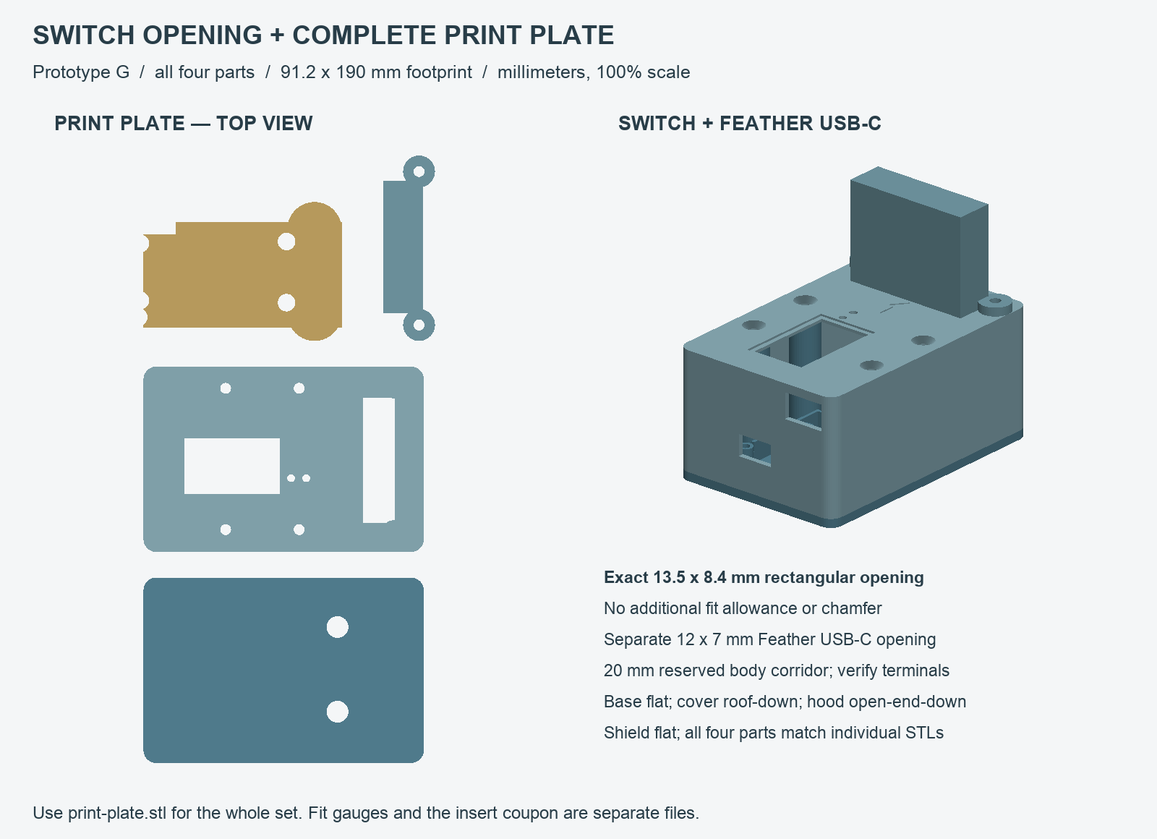
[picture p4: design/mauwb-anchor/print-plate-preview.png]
Print plate


## Hardware

| Quantity | Hardware |
| --- | --- |
| 4 | M2 × 6 mm pan-head screws: two per board; modeled head up to 4 mm diameter × 1.6 mm high |
| 4 | M2 heat-set inserts, 3 mm long, approximately 3.2 mm outside diameter; validate with coupon |
| 6 | M3 × 4 × 5 mm heat-set inserts: four in base, two in cover for hood |
| 4 | Existing M3 × 8 mm 90° countersunk lid screws, inserted from above |
| 2 | M3 × 8 mm pan/button-head hood screws |
| 2 | Existing screws matching the camera cage threads, with suitable engagement length |
| As needed | Thin battery pad, insulated direct wires, optional 0.5 mm PET display window |

M2 pockets are a **3.0 mm trial diameter**, **3.8 mm deep**, with a **2.2 mm core continuing another 1 mm**. The M2 screw tip clears the core bottom by 0.4 mm with the assumed 1.6 mm PCB. The 5 mm-diameter posts support the board around its holes. Verify the selected inserts and screw heads before printing the full base; insert dimensions vary.

Use a precision screwdriver with a shaft no wider than the modeled **4 mm** for the board screws. Remove the STM32 before accessing the Feather screws. The lid screws use a separate 8 mm shaft clearance check.

M3 insert pockets retain the **4.6 mm trial diameter** and **5 mm depth**, with a 3.4 mm screw core continuing 1.2 mm. Base closure posts are 9.4 mm in diameter and end at **z=38.1 mm**, 0.2 mm below the lid seats. Screw centers are **(22,-6.2), (45,-6.2), (22,38), (45,38) mm**. Four M3 × 8 countersunk screws engage the full 4 mm insert length. No underside access is needed to open the case.

## Camera mounting and alignment

Mount on the **moving camera or cage**, with +X toward the lens, Y across the camera, and +Z upward. Do not use the stationary handle-side CAN adapter mount for the anchor: it would not preserve the camera-to-anchor orientation needed by this controller. The recessed arrow points toward the lens. The two antenna elements must remain **side by side and level**, with their broad face looking forward.

The cage holes are **(57,3.06) and (57,29.54) mm** in assembly coordinates. They have **6.8 mm smooth bores**, **10.2 mm head recesses**, and **2.4 mm flat seats** above the cage-facing underside. These fit the user's approximate **6.23 mm shaft / 9.38 mm head diameter / 6.23 mm head height** envelope. The shield remains at z=9.3 mm, giving **0.67 mm head clearance**. The gauge checks these seats and hole spacing, not the strength of the loaded assembly.

For a flat-under-head cage screw without a washer, protrusion below the case equals under-head length minus **2.4 mm**. Check cage thread depth and engagement; the thread designation remains unknown. The cage must support the base around both holes. Do not use screw force to pull an uneven case flat. The screw heads are beneath the shield and electronics, so fasten the empty base first.

The radio front face stays flush with the 72 mm carrier edge: the approximate 4 mm-thick module occupies x=68…72 mm. Its top is user-measured **42.11 mm above the STM32 underside**. The hood leaves nominal **3 mm air clearance**, with **1.2 mm plain-plastic walls**. The header envelope is provisional; verify it and the new keepers against the actual board.

The Feather antenna is below the STM32 board in this layout. **Mechanical clearance is not an RF keep-out validation.** Check ESP-NOW reception over full gimbal travel and compare bare/enclosed UWB bearing before relying on the stack. Keep the UWB antenna pair above cage metal. Check zero bearing with the tag centered in the lens, then verify left/right sign. Rebalance for the taller enclosure and confirm clearance through the entire gimbal movement. Alignment to the cage-hole midpoint does not prove alignment to the lens; that offset has not been measured. The current one-angle controller still assumes an approximately level camera.

## Printing and assembly

Use plain unfilled PETG for the working parts; avoid conductive/carbon/metal fillers around the antennas. Start with a 0.4 mm nozzle, 0.2 mm layers and four perimeters. Print the shield solid. Base prints flat, cover roof-down, hood open-end-down and shield flat. Inspect the approximately **1.1 mm front-keeper overhangs**, hood roof bridge, countersinks and window recess in the slicer. These orientations are not printer-tested; the enclosure is not weather-sealed.

1. Check cage fit with the mounting gauge if not already verified. Print the M2/M3 insert and switch coupons before the full set. Check the actual Feather board revision, mounting holes and USB plug against the source dimensions.
2. Print all four revision-G parts. Trial-fit them empty. Install four M2 inserts in the two Feather and two STM32 rear posts; install four M3 inserts in the lid posts and two in the cover's hood mounts. Let them cool with electronics removed.
3. Fasten the empty base to the cage. Add the thin pad and battery without compressing the pouch. Route its lead through the cradle/shield notch. Lower the shield over all posts; its new openings clear the Feather supports. Check both cage heads remain below it.
4. Lower the Feather onto its four supports with USB toward the rear opening. Engage its two front locating pins and install the two rear M2 screws. The board must sit flat. Fit the switched battery harness with the cell unplugged, then connect Feather BAT/GND to the anchor battery pigtail and route the UART lead before the STM32 blocks access.
5. Hold the STM32 level, slightly rearward, with its front edge beneath the two keepers. Slide it forward 1.5 mm to align the rear holes, then install its two M2 screws. Check the keepers overlap only clear PCB edge and touch neither header nor antenna. No fasteners enter the covered front holes. Keep wire slack clear of the Feather antenna and solder joints.
6. Fit the rocker in series with the battery harness positive lead; keep the negative lead continuous and leave Feather EN unconnected. Insulate both terminals, which now carry battery current. Leave enough flexible lead to support and unplug the cover. Check the approximate 15 mm installed depth, flange and clips physically. No loose lead may cross a screw boss or press on the battery.
7. Lower the cover vertically around the antenna. Close its four M3 screws from above without forcing the joint. Fit the hood with its two M3 screws. Check USB plug reach and switch action. An optional 0.5 mm PET window can be bonded into the OLED recess.
8. Verify power-off/charging behavior, wireless link loss handling, alignment and balance before tracking.

For service, remove the four lid screws and lift the cover/hood vertically while supporting the switch lead. Unplug all USB cables and the battery; the battery-side rocker terminal stays live when OFF. Release the two STM32 screws, slide the board rearward **1.5 mm**, then lift it, supporting or unplugging its leads. Its antenna can remain installed within the modeled envelopes. Remove the two Feather screws and lift it vertically off the front pins. The shield and battery can then be removed while the base stays on the cage. Remove both boards and shield to reach the cage screws.

## Evidence and validation limits

- [Adafruit Feather ESP32-S3 PCB CAD](https://github.com/adafruit/Adafruit-Feather-ESP32-S3-PCB/blob/main/Adafruit%20ESP32-S3%208MB%20No%20PSRAM.brd): **50.8 × 22.86 mm outline**, 2.54 mm corner radii, rear hole centers (2.54,2.54)/(2.54,20.32), front centers (48.26,1.8415)/(48.26,20.955); USB/JST/module XY footprints. Read 2026-10-04; downloaded-file SHA-256 recorded in measurements. Component heights are provisional.
- [Pinned Makerfabs carrier CAD](https://github.com/Makerfabs/UWB-AOA-with-Display-STM32F103C8T6/tree/34b9705edcb7feca83f652280047847d4bc03c34/Hardware): **72 × 32.6 mm PCB**, 3 mm holes at (2,2), (2,30.6), (70,2), (70,30.6), display and connector XY. Compare against the delivered revision. Its flat tag footprint is not used for the anchor's upright radio envelope.
- [X3 module manual](https://github.com/Makerfabs/UWB-AOA-with-Display-STM32F103C8T6/tree/34b9705edcb7feca83f652280047847d4bc03c34/Doc): 33 × 36 × 3.5 mm module listing; user supplied 33 mm width, approximate 4 mm lower depth, flush-front position and 42.11 mm installed height.
- Battery packed dimensions **35.5 × 29 × 4.65 mm** are user measured. The cradle adds 1 mm per side, with a 0.3 mm pad and 1.85 mm total vertical allowance under the shield. [PKCELL LP503035 specification](https://www.batterypkcell.com/uploads/LP503035-500mAh-3.7V.pdf) identifies the electrical cell limits; protection and connector polarity still require confirmation.

The build verifies closed printable meshes, expected component counts, positive volume and agreement between the plate and individual parts within 0.002 mm export rounding. Mesh probes inspect cage holes/seats, lid countersinks, blind base floors, board insert openings, Feather locating pins, STM32 keepers and both faces of the new USB aperture. The rocker check inspects exact corners and ±0.01 mm around every edge on both wall faces, without adding tolerance to its geometry.

OpenSCAD checks printed-part, component and fastener interference, including the Feather and four M2 board screws. Separate checks cover the 20 mm switch corridor, trial USB plug corridor, lid-driver access, sampled lid removal, continuous vertical radio/header sweep, and sampled STM32 slide/lift and Feather lift paths. Mating faces may yield numerical zero-volume intersections. Board service paths are sampled, not a full swept scan. Actual flange/clips/terminals, flexible wiring, insert knurls, camera/cage surfaces and manufacturing variation are excluded. Passing checks does not establish real retention strength, print fit, RF performance, thermal performance, balance, charging compatibility or runtime.

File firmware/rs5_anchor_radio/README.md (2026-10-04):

# Camera-side UWB radio

Battery-powered Adafruit Feather ESP32-S3 8 MB / no PSRAM beside the stock STM32 anchor. Acts as an **optional UWB peripheral** to the RS5-body master: receives TXD1/PA9 on RX/GPIO38 at 115200 and answers the master's requests with fresh measurements over paired ESP-NOW. No CAN interface or USB-host requirement. Once paired, powering it on makes its reports available automatically; the master decides when to follow.

Flash [rs5_anchor_radio.ino](rs5_anchor_radio.ino) onto the **camera** ESP32 using the [main README's flashing and pairing steps](../../README.md#flash-both-esp32s). First upload discovers its STA MAC; after generating the shared pairing file, rebuild/upload both ESP32s. Without configuration, `radio_ready=0` is expected. USB serial at 115200 prints the camera MAC once per second.

See [wireless wiring, shared battery and charging](../WIRELESS_UWB.md). The [revision G enclosure](../../design/mauwb-anchor/README.md) includes this board; physical fit and wireless operation remain unverified.

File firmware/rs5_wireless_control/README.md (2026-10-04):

# Body-side wireless UWB controller

Adafruit Feather ESP32-S3 8 MB / no PSRAM on the fixed RS5 body, acting as **master**. Builds the same [manual/Control Desk controller](../rs5_manual_control/README.md) with paired ESP-NOW UWB input instead of the anchor UART wires. It polls the optional camera node and owns tracking and all CAN commands. Manual control works without that node; its arrival offers UWB follow without taking control. Existing CAN wiring and operator leases remain in effect; boots disarmed.

Flash [rs5_wireless_control.ino](rs5_wireless_control.ino) onto the **RS5-body** ESP32 using the [main README's flashing and pairing steps](../../README.md#flash-both-esp32s). First upload discovers its STA MAC (`help` over USB serial at 115200); after generating the shared pairing file, rebuild/upload both ESP32s. Without configuration, `radio_ready=0` is expected.

See [wireless wiring and power](../WIRELESS_UWB.md). This build needs local pair configuration and the existing USB/Control Desk session. The moving camera has its own Feather and shared anchor battery; its supply is independent of this board. The user's wired Waveshare/Mill-Max tracking path is validated; the added wireless hop still needs a physical test.

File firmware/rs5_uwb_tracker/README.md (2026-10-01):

# Makerfabs AoA → Feather → RS5 pan tracking

**For the existing Control Desk UI and PS4 X toggle, use the [combined manual + UWB firmware](../rs5_manual_control/README.md) and [connection/setup guide](../../control_ui/UWB_SETUP.md).** This page describes the older standalone console prototype. Its motion envelope and console-disconnect behavior differ from the UI version.

This sketch adds a first pan-tracking controller for the **Adafruit Feather ESP32-S3, 8 MB flash / no PSRAM**, the **original Makerfabs MaUWB STM32 AoA Development Kit**, and the existing Waveshare CAN interface. It is a prototype: compiled and tested on the host, but **not yet tested with the physical kit or RS5**. RS5 connector verification in the [main project](../../README.md#termination-and-first-electrical-checks) remains necessary.

The default build is **preview only**: UWB input and proposed steering are displayed, and CAN stays listen-only. A separate, explicitly enabled build adds joint-angle queries and manually armed motion. Flash this sketch or the [CAN monitor](../README.md) separately; they are alternative Feather applications.

## Which board goes where

- **Anchor:** the board with the UWB-X3-AOA two-antenna module. Mount it on the moving camera platform so it pans with the lens, close to the lens centerline. It measures the direction to the tag.
- **Tag:** the board with the UWB-X3-MAX module. The subject carries it, with the antenna unobstructed.
- **Feather:** reads the anchor's measurements and computes yaw speed, then uses the Waveshare transceiver to communicate with the RS5.

Both Makerfabs boards use STM32F103C8T6 controllers. Keep their factory anchor/tag firmware initially: it already performs UWB ranging and AoA processing and sends results over UART. **No STM32 reflashing or ST-Link is needed for this version.** The new tracking program runs on the Feather.

The anchor must rotate with the camera for this controller's bearing feedback to work. A fixed handle-mounted anchor needs a different coordinate transform and camera-orientation feedback. Align the antenna measurement plane horizontally and keep the camera approximately level for the initial test. Avoid placing the antennas directly against the camera's metal body. Rebalance the gimbal after mounting the anchor, and route power/signal cables with clearance throughout the intended motion.

This kit measures **one angular dimension**, not both azimuth and elevation. The controller changes yaw only; it does not follow vertical movement, center a face in the image, or search through a full revolution. Makerfabs specifies approximately ±60° coverage and ±5° angular error; these are vendor specifications, not measurements here. Start with a wide lens and broad framing. A tag outside the valid field causes disarming, requiring manual reacquisition and re-arming.

## Wiring

Keep the existing CAN wiring:

| Feather pad label | Connect to |
| --- | --- |
| **5 / GPIO5** | Waveshare CAN TX |
| **6 / GPIO6** | Waveshare CAN RX |
| **3V** | Waveshare 3.3V |
| **GND** | Waveshare GND and verified RS5 GND |

Add only these two wires for the anchor:

| Makerfabs anchor | Feather |
| --- | --- |
| **TXD1**, STM32 PA9, schematic J2 pin 4 | **RX**, GPIO38 |
| **GND**, schematic J2 pin 2 | **GND** |

Use the actual board silkscreen and the schematic to identify the header: the pin numbers above are schematic identities, not a left-to-right count from an unspecified viewing angle. They come from the vendor's **V1.1** schematic; confirm the revision of the kit that arrives.

Leave the Feather **TX / GPIO39 unconnected**. Do not connect to anchor RXD1/PA10: its onboard CH340 USB-to-UART chip already drives that input. The program receives at **115200 baud, 8 data bits, no parity, 1 stop bit**, with no flow control, and never sends anchor commands on this wire. TX-to-RX is correct here because this is UART; the CAN transceiver's TX/RX wiring has different signal roles.

Power the Feather and anchor through their own USB connectors, with common ground. Power the tag independently by its USB-TTL connector or supported battery. Do not join their 3.3 V/5 V supply rails, and keep RS5 accessory VCC disconnected. The Feather's 3V output powers only the CAN breakout in this setup.

Before joining TXD1 to the Feather, disconnect power and use continuity mode to verify the selected ground/header pads against the schematic. Then power the anchor alone and use DC-voltage mode to check TXD1 relative to GND: this is a **3.3 V logic** signal, not RS-232 or a 5 V output. A meter may show an average while data is flowing; it cannot decode UART or prove its voltage peaks. Do not use resistance mode on powered boards. Remove power before making the final wiring connection.

## Prepare the Makerfabs kit

First verify ranging using the factory setup, independently of the RS5:

1. Connect the anchor's **USB-NATIVE** port to the computer; power the tag through USB-TTL or a supported battery.
2. In Makerfabs' **AOA System** application, discover and bind the actual tag. Keep **one anchor paired to one tag**; the vendor specifically warns that multiple bindings prevent normal operation.
3. Verify that displayed distance and horizontal bearing change as the tag moves. Use the factory calibration initially. Do not substitute raw phase (`P`) for bearing.
4. Ensure the anchor emits **JSON mode (`USER_CMD 0`)**. This receiver does not implement the alternative binary output format.

The stock anchor also accepts these text commands through its USB-NATIVE serial port, useful on systems without the vendor GUI. Use 115200 and **CR+LF** line endings. Send commands one at a time and read their replies:

```text
GETDLIST
GETKLIST
USER_CMD 0
SAVE
```

`GETDLIST` reports discovered 64-bit tag addresses and clears that discovery list; `GETKLIST` reports saved bindings including `a16`, the short address used by the Feather. If there is no binding, the stock command syntax is:

```text
ADDTAG YOUR_16_HEX_DIGIT_TAG_ADDRESS 1234 1 1 0
GETKLIST
SAVE
```

Replace the long-address placeholder with the tag actually discovered. `1234` is an example chosen short address, followed by fast/slow multipliers of 1 and mode 0. Do not add another binding when one already exists. Configure the anchor while the tracker is disarmed; configuration replies can interrupt the measurement stream.

Verify regular reports while the tag is stationary as well as moving, preferably every 100 ms or faster. The tracker requires three valid reports and stops accepting a fix after 300 ms without a new report. If updates are too slow, investigate the actual firmware/configuration before increasing that timeout. Factory revisions can differ; this implementation follows the source revision listed below.

## Build and test the preview first

Open [rs5_uwb_tracker.ino](rs5_uwb_tracker.ino) in Arduino IDE with **Adafruit Feather ESP32-S3 No PSRAM** selected, Arduino-ESP32 **3.3.11**, 8 MB flash, TinyUF2 8 MB partition, TinyUSB and USB CDC enabled. No additional Arduino libraries are required. Keep `RS5_ENABLE_MOTION` at **0**. Board selection/upload details are in the [CAN monitor instructions](../README.md#flash-with-arduino-ide).

From the repository root, the equivalent CLI build is:

```sh
arduino-cli compile \
  --fqbn esp32:esp32:adafruit_feather_esp32s3_nopsram \
  --warnings all \
  --build-path "$PWD/tmp/tracker-preview-build" \
  --output-dir "$PWD/tmp/tracker-preview" \
  firmware/rs5_uwb_tracker

arduino-cli board list

arduino-cli upload \
  --fqbn esp32:esp32:adafruit_feather_esp32s3_nopsram \
  --port YOUR_FEATHER_PORT \
  --input-dir "$PWD/tmp/tracker-preview" \
  firmware/rs5_uwb_tracker
```

Upload with the gimbal disconnected. Replace `YOUR_FEATHER_PORT` with the detected Feather port, not the anchor's port. Open the Feather's USB serial monitor at 115200, with newline or CR+LF endings. The program announces each observed tag until you explicitly select one:

```text
tag 1234
status
```

Use the real `a16` displayed by the anchor or the Feather. Selection is deliberately not automatic and is not saved across resets. Status repeats every 500 ms and includes bearing, range, proposed yaw speed, and tracking state. Missing joint telemetry is expected in preview mode.

With CANH/CANL still disconnected from the RS5:

1. Place the tag about 2–5 m ahead, at roughly the anchor's height. Check that the selected tag reaches `state=tracking` and bearing is near zero at the center of the lens view.
2. Move the tag gently left and right. Check that bearing crosses zero and the proposed speed changes sign. Rotation of the anchor toward a stationary tag should reduce the bearing magnitude.
3. Turn off the tag. The reported state should become stale and proposed speed return to zero. Bring it back and verify three new reports are required. Repeat with tag movement near the edge of the valid field.
4. Confirm that `probe` and `arm +` are refused by this build. No command enables CAN transmission in preview firmware.

If center alignment has a consistent offset, measure it over several seconds and set `zeroDegrees` in [shared TrackingCore.h](../shared/TrackingCore.h), then rebuild. That compensates mounting offset, not varying radio multipath or parallax. Validate the installed mount with the camera powered, since its body and nearby electronics can affect measurements.

## Optional motion build, after electrical and preview checks

The preview cannot move the gimbal. To build the separate motion-capable version:

```sh
arduino-cli compile \
  --fqbn esp32:esp32:adafruit_feather_esp32s3_nopsram \
  --warnings all \
  --build-property compiler.cpp.extra_flags=-DRS5_ENABLE_MOTION=1 \
  --build-path "$PWD/tmp/tracker-motion-build" \
  --output-dir "$PWD/tmp/tracker-motion" \
  firmware/rs5_uwb_tracker
```

Upload using the preview command with `--input-dir "$PWD/tmp/tracker-motion"`. In Arduino IDE, the equivalent is changing the sketch's default `#define RS5_ENABLE_MOTION 0` to `1`. Both builds boot **listen-only and disarmed**.

Start with a balanced gimbal on a stable stand, unlocked for normal operation, with a clear motion area and accessible RS5 power control. Confirm the connector, termination, CAN bitrate and ground using the [electrical procedure](../../README.md#termination-and-first-electrical-checks). Select the tag, then send:

```text
probe
status
```

`probe` changes to normal CAN mode and sends **joint-angle queries only**, every 200 ms. It acknowledges CAN traffic but does not request movement. Require `joint=fresh` and plausible yaw values that change correctly with gimbal orientation. Replies must match the outstanding query sequence, both DJI CRCs, command, successful return code, and joint-angle data type. A quiet passive bus can be inconclusive; failed queries are not grounds to bypass these checks.

For the first movement, put the tag only about 5–10° off center, with the gimbal near its center. Send `arm +`, observe briefly, then `stop`. The camera should move toward the tag and reduce bearing magnitude. If it moves away, stop immediately and use `arm -` for the next small test. This explicitly calibrates the relationship between the installed sensor orientation and DJI's yaw direction; it is not established by the source code. Confirm both sides and verify `stop`, tag power loss, and subsequent manual re-arming before trying continuous tracking.

| Command | Effect |
| --- | --- |
| `tag HHHH` | Disarm, select that short tag address, reacquire three reports |
| `status`, `help` | Show state or commands |
| `probe` | Motion build only: enter normal CAN and query joint angles; remain disarmed |
| `arm +`, `arm -` | Motion build only: arm with selected direction after fresh tag/joint checks |
| `stop` | Disarm, request zero speed, then release speed control |
| `listen` | Disarm and return to listen-only CAN |

No autonomous startup or re-arming is implemented. Closing the USB monitor **does not stop an already armed tracker** if the Feather remains powered. Use `stop` before disconnecting the console; keep the physical RS5 power control available during tests.

## Control behavior and limitations

The controller calculates `atan2(Xcm, Ycm)` from the anchor's processed coordinates, applies a 0.25 s smoothing time constant and 3° deadband, then requests yaw speed proportional to the remaining angular error. Defaults cap speed at **15°/s**, acceleration at **45°/s²**, valid bearing at **±55°**, and distance at **0.75–20 m**. Arming starts speed from zero. Commands repeat at 20 Hz with roll/pitch speed zero. Tuning constants are in `firmware/shared/TrackingCore.h`, shared with the UI firmware.

Stale tag data (>300 ms), invalid selected-tag range/bearing, large angular jumps, malformed/partial UART reports, serial overflow, stale joint telemetry (>500 ms), loop stalls, and CAN faults disarm. Duplicate and recent out-of-order ranging sequences cannot refresh the fix. Unselected tags do not refresh it either. Disarming normally sends zero-speed and release packets. A CAN fault stops the driver and discards its queued commands; it may make sending a stop impossible.

The legacy DJI SDK states that each speed command lasts at most **0.5 s**. This fallback behavior, stop/release behavior, yaw direction, and RS5 compatibility all require physical verification. Source review and host tests do not prove that a real gimbal will stop on a broken connection. The ±85° joint-yaw envelope, slowing within 10° of its edge, is a software bound relative to reported gimbal joints; it is not a guaranteed mechanical/cable limit. Adjust it to the actual mounting clearance after measurement. The program does not modify the RS5's stored modes or limits.

The Makerfabs JSON link has length framing but **no checksum**. The parser validates structure, required fields, bounds and sequence progression; plausible corrupted readings or multipath errors can still pass. This is supervised prototype tracking, not a guarantee that the subject will always remain framed. RF occlusion, limited field of view, vertical movement and a rapidly moving subject can all break tracking.

## Validation and source references

Host tests exercise vendor-format input, truncated/malformed packets, integer bounds, noise, sequence and timer wraparound, tag selection, stale-data stopping, rate limits, and a simulated yaw plant. DJI packet generation is checked against the independent SDK v2.5 section 3.3 example; every single-byte corruption of a sample reply is rejected. The simulator checks controller behavior, not RF performance or motor dynamics.

```sh
mkdir -p tmp
c++ -std=c++17 -Wall -Wextra -Werror \
  -fsanitize=address,undefined -fno-omit-frame-pointer \
  firmware/tests/tracker_test.cpp -o tmp/tracker_test
tmp/tracker_test
```

Both preview and motion builds compile for the exact Feather profile with Arduino-ESP32 3.3.11. The core emits its existing command-line warning about the default hyphenated TinyUF2 partition macro. No hardware was flashed during development.

- [Makerfabs product](https://www.makerfabs.com/mauwb-stm32-aoa-development-kit.html) and [official repository](https://github.com/Makerfabs/UWB-AOA-with-Display-STM32F103C8T6): original STM32 kit, not Gen2 or the unrelated AT-command ranging modules.
- Source reviewed at commit `34b9705edcb7feca83f652280047847d4bc03c34`: `Firmware/stm32cube/CubeIde/projectN/DW/PDoA/json_2pc.c` defines `JS` + four ASCII hex length digits + JSON + CR/LF. `D`, `Xcm`, `Ycm` are centimeters; `P` is phase data, and `X/Y/Z` are acceleration fields. `DW/Examples/ds_twr_sts_sdc_responder.c` supplies processed coordinates. `APP/Generic_cmd.c` mirrors output to USB/UART; `Core/Src/usart.c` configures USART1 at 115200. The stock Keil `Anchor.zip` contains the same UART/JSON output path.
- Vendor `Hardware/UWB AOA with Display STM32F103C8T6 V1.1.sch`: J2 pin 4/TXD1 connects to STM32 PA9 and the CH340 receive input; J2 pin 3/RXD1 connects to PA10 and CH340 transmit; J2 pin 2 is GND.
- [Adafruit Feather pinout](https://learn.adafruit.com/adafruit-esp32-s3-feather/pinouts) and Arduino-ESP32's `adafruit_feather_esp32s3_nopsram` variant: RX=38, TX=39, GPIO5/6 chosen for CAN.
- [Local DJI SDK v2.5](../../references/dji-r-sdk-v2.5.pdf), sections 2.3.4.2–3 and 3: speed control, joint queries, CAN fragmentation and CRCs. The official SDK archive's CRC headers initialize their reflected implementation with `0x3aa3` (CRC16) and `0x00003aa3` (CRC32), the reflected forms of the PDF's XorIn values. The known-answer test checks this distinction.

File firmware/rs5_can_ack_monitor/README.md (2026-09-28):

# RS5 CAN acknowledgment diagnostic

This is a separate sketch for the Adafruit Feather ESP32-S3, 8 MB flash / no PSRAM, and Waveshare SN65HVD230. It tests whether automatic CAN acknowledgments allow the RS5 to progress beyond repeated frames seen by the [passive monitor](../README.md).

**This is not electrically passive.** It starts in normal CAN mode at 1,000,000 bit/s and automatically acknowledges valid received frames and participates in CAN error signaling. It has no application transmit calls, DJI packet generator, queries, or movement commands. Its application TX queue is disabled. Automatic ACKs can change what the RS5 sends; they do not indicate that this program understands or accepts a DJI command.

## Wiring and use

Keep the verified wiring and termination from the passive test:
Feather 5/GPIO5 to Waveshare CAN TX, 6/GPIO6 to CAN RX, 3V to 3.3V, and shared Feather/Waveshare/RS5 ground. RS5 CAN-H/L go to CANH/CANL. Leave both RS5 VCC leads insulated. Fit or change the adapter with all power removed.

Close any other serial monitor before uploading. Observe the gimbal with its motion area clear; this firmware does not request movement, but the gimbal retains its own startup and controls.

```sh
arduino-cli compile \
  --fqbn esp32:esp32:adafruit_feather_esp32s3_nopsram \
  --warnings all \
  --build-path "$PWD/tmp/firmware-build-ack" \
  --output-dir "$PWD/tmp/firmware-ack" \
  firmware/rs5_can_ack_monitor

arduino-cli upload \
  --fqbn esp32:esp32:adafruit_feather_esp32s3_nopsram \
  --port YOUR_PORT \
  --input-dir "$PWD/tmp/firmware-ack" \
  firmware/rs5_can_ack_monitor

arduino-cli monitor --port YOUR_PORT --config baudrate=115200
```

Use `arduino-cli board list` to find the port. The banner says `NORMAL CAN`; status says `ACK_MONITOR RUNNING`.

Commands `h`/`?`, `s`, and `p` show help, status, and toggle frame previews. None change CAN mode. **Closing the serial monitor does not stop acknowledgments.** Restore the original `rs5_can_monitor` sketch to return to electrically passive listening.

The same preview limit of 20 frame lines per second applies; counters include omitted previews. `id426` counts standard data frames on the observed ID, alongside the legacy `id222`/`id223` counters. IDs and eight-byte fragments are not decoded as DJI messages, and no particular meaning is assigned to 0x426. Timestamps are application dequeue times. This is not a lossless capture.

Compare received-frame rate, IDs/payloads and the change in cumulative `bus_errors` over 10–15 seconds. A reduced repetition rate or advancing payloads after enabling ACKs supports the missing-acknowledgment explanation; it does not prove SDK query/control compatibility. The monitor does not initiate bus-off recovery.

## Initial evidence

The user's passive RS5 test reported repeated standard ID 0x426 with payload `55 45 04 DE E5 06 00 00`. Between 700013 and 715013 ms it received 115,383 frames while `bus_errors` stayed at 290 and receive-loss counters stayed at zero. This prompted this diagnostic; the frame's application meaning remains unknown.

[Espressif TWAI operating modes](https://docs.espressif.com/projects/esp-idf/en/v5.4/esp32s3/api-reference/peripherals/twai.html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) describe normal versus listen-only behavior.

## Hardware validation — 2026-09-28

Compiled with Arduino-ESP32 3.3.11 for the exact Feather profile: 359,442 bytes of application flash and 58,696 bytes of static RAM. The core emitted its existing warning about the hyphenated TinyUF2 partition macro. Upload succeeded and the flasher verified all written data.

The connected Feather reported `ACK_MONITOR RUNNING`. In a 28-second interval (30013–58013 ms), `rx` increased from 1360 to 2631: about 45.4 frames/s, compared with about 7692 frames/s in the earlier passive interval. All sampled `bus_errors`, receive-loss counters, REC and TEC were zero. Printed frames remained on 0x426, but the payloads progressed through multiple fragments and changing header bytes. This strongly supports missing acknowledgments as the earlier repetition cause. It does not identify the payload's meaning or validate DJI SDK queries or motion control; `id222` and `id223` remained zero.

The console sample is saved locally in `tmp/rs5-can-ack-20260928.log` (ignored by Git). It includes the 20-frame-lines/s display limit and is not a full bus capture. The serial monitor was closed after verification; the flashed firmware continues acknowledging while powered.

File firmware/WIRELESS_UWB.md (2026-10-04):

# Wireless camera-to-RS5 connection

Electronics revision, 2026-10-04. One additional **Adafruit Feather ESP32-S3, 8 MB / no PSRAM**, lives with the STM32 anchor on the moving camera. The existing Feather and CAN transceiver stay on the fixed RS5 body. A **single-cell 3.7 V / 500 mAh LiPo**, connected to and charged by the camera Feather through an inline positive-lead rocker, powers both camera-side boards. No power, UART or ground wire crosses a moving gimbal joint.

**Working baseline:** the user confirmed on 2026-10-04 that `anchor → ESP32 → Waveshare → Mill-Max harness → RS5` successfully tracked the tag. This revision implements the camera-ESP32 → body-ESP32 radio hop while retaining that CAN interface. Physical wireless following and the combined camera-side power system remain unverified. [Flash each ESP32 and pair them](../README.md#flash-both-esp32s).

The camera Feather relays measurements using encrypted, paired ESP-NOW. The body Feather calculates bearing and runs the existing pan controller. Keeping tag ID, ranging sequence and distance alongside X/Y coordinates preserves the existing validity checks. This is the tag's bearing relative to the camera, not an absolute gimbal joint angle. The stock anchor/tag firmware and bindings remain in place.

**The body Feather is the master; the camera Feather is an optional measurement peripheral.** The master initiates each request and owns tag selection, tracking and CAN control. The camera only answers with sensor data. Manual mouse/PS4 control works without the camera or a radio pairing. Once paired, camera reports are detected automatically whenever that node is powered and in range. Control Desk offers follow after tag selection and a fresh fix; detecting or reconnecting a camera never starts motion or interrupts an active manual gesture. UWB loss stops active follow and requires a fresh operator action after reacquisition.

```mermaid
flowchart LR
  Tag[Subject's UWB tag] -. UWB .-> Anchor
  subgraph Moving[Moving camera: one enclosure]
    USB[USB charging] --> Camera[Camera Feather ESP32-S3]
    Cell[1S 500 mAh battery] <-->|positive lead| Rocker[Battery rocker]
    Rocker <--> Rail[Switched battery positive]
    Camera <-->|battery JST / BAT| Rail
    Rail -->|BAT positive| Anchor[STM32 AoA anchor]
    Anchor -->|short internal TXD1 and GND| Camera
  end
  Camera <-. ESP-NOW .-> Body
  subgraph Fixed[Fixed RS5 body]
    Body[Body Feather ESP32-S3] --> CAN[Existing SN65HVD230]
    CAN -->|CAN-H and CAN-L| Harness[Mill-Max pin harness]
    Harness --> RS5[RS5 RSA port]
  end
  Desk[Control Desk / PS4] -->|USB to fixed body| Body
```
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

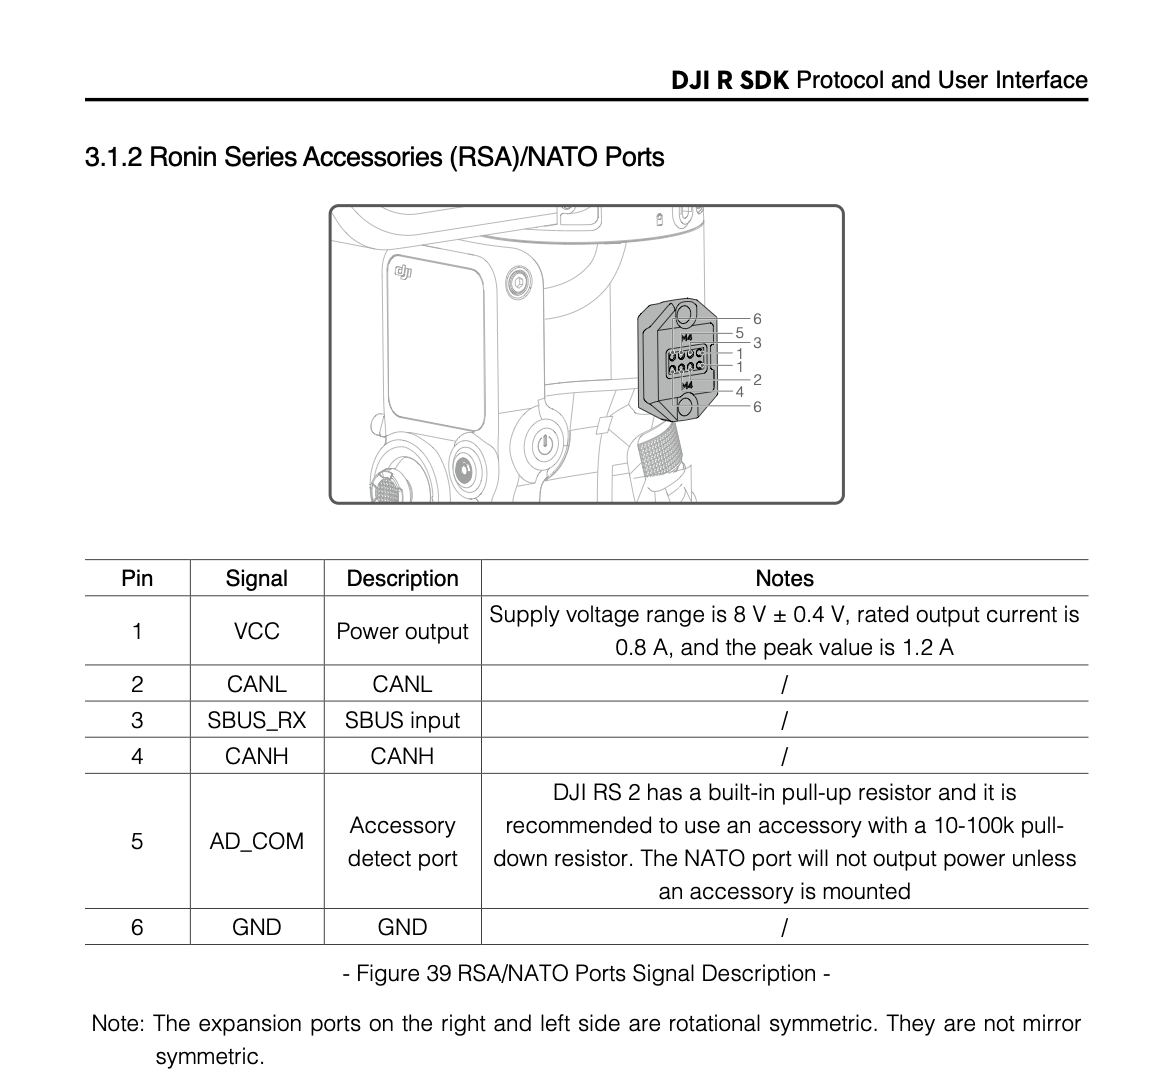
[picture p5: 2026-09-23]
references/dji-sdk-pinout.png

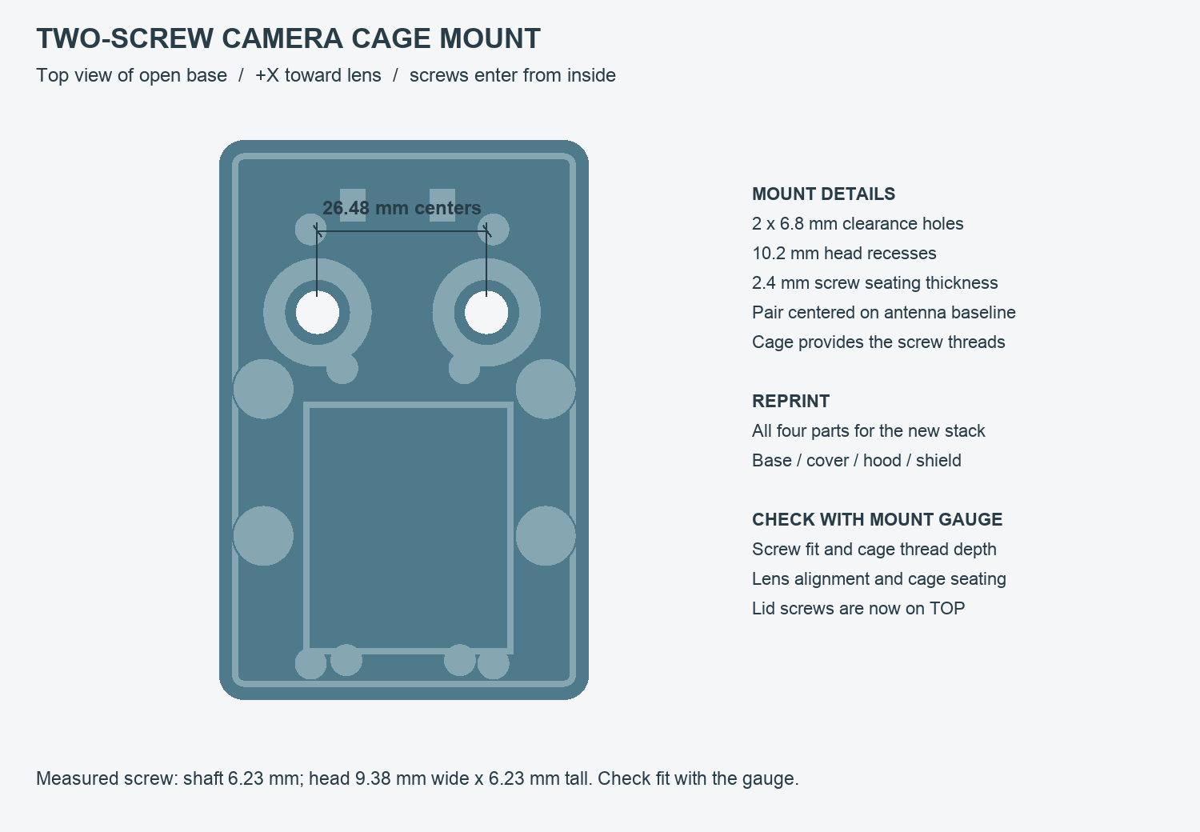
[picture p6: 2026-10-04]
design/mauwb-anchor/mount-preview.png

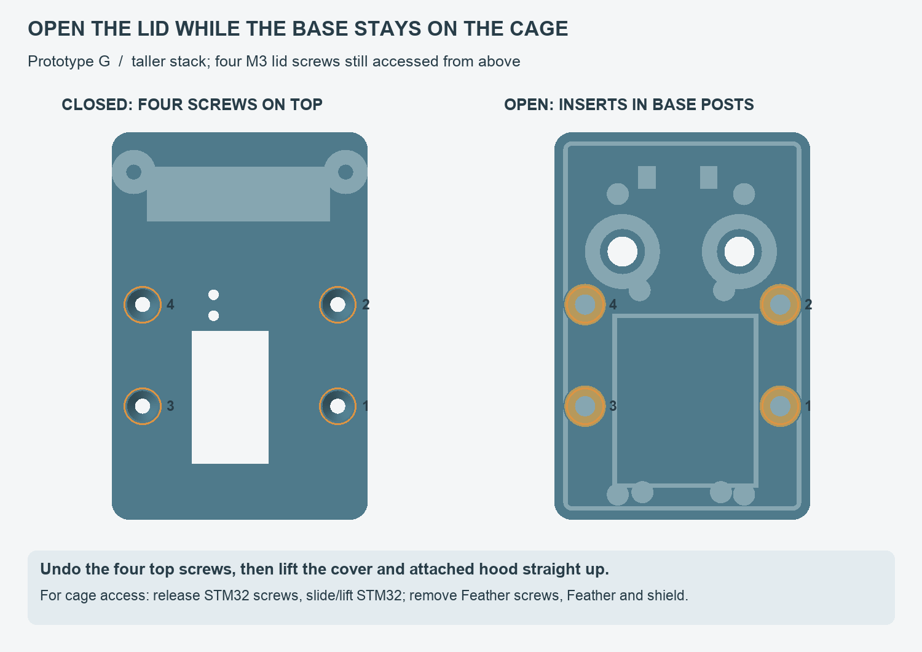
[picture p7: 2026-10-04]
design/mauwb-anchor/closure-preview.png

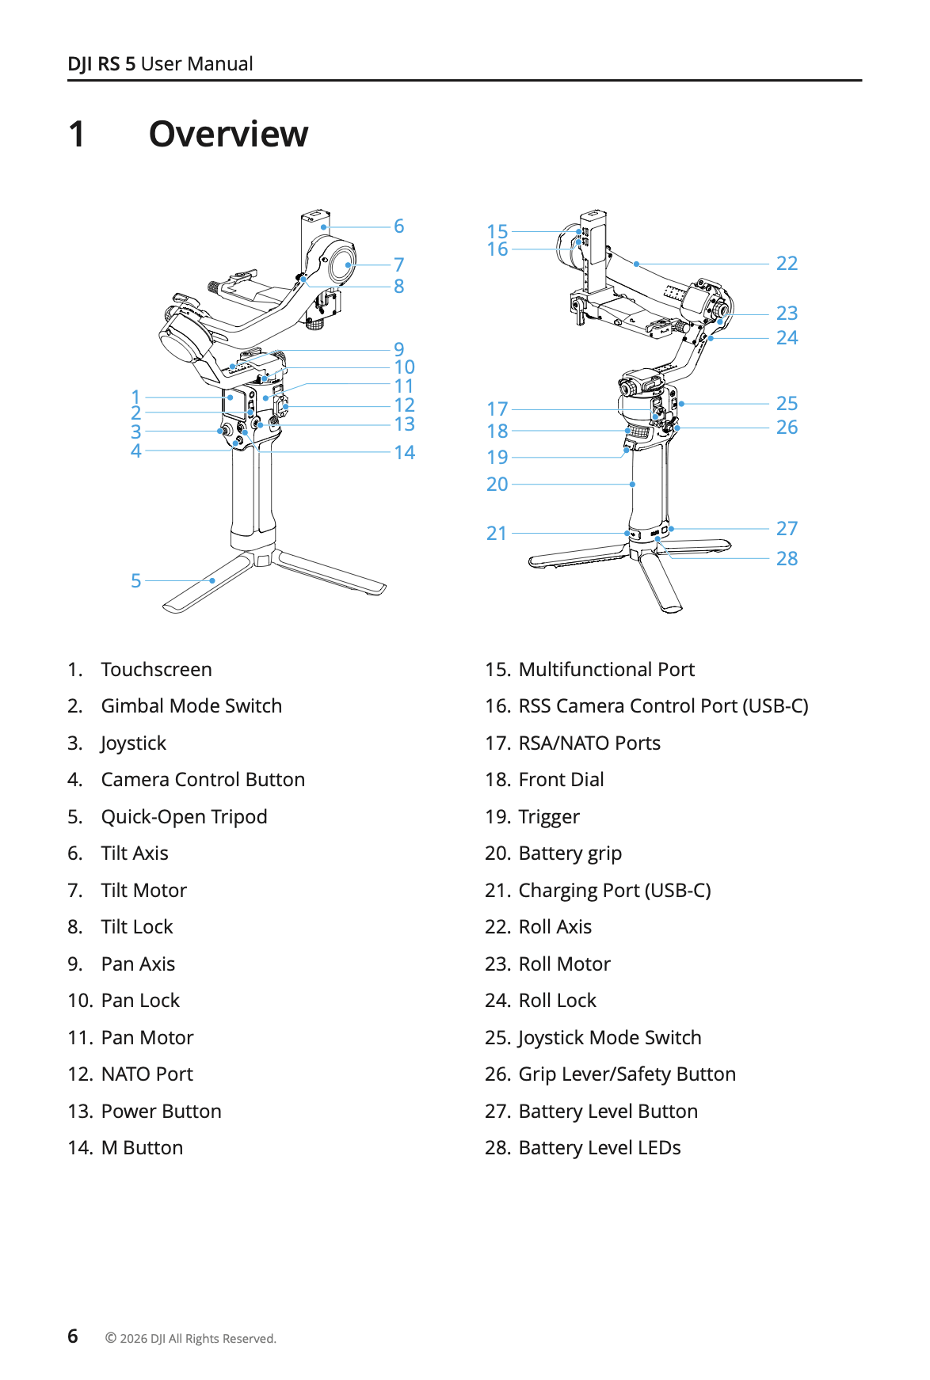
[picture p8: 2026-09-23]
references/dji-rs5-overview.png

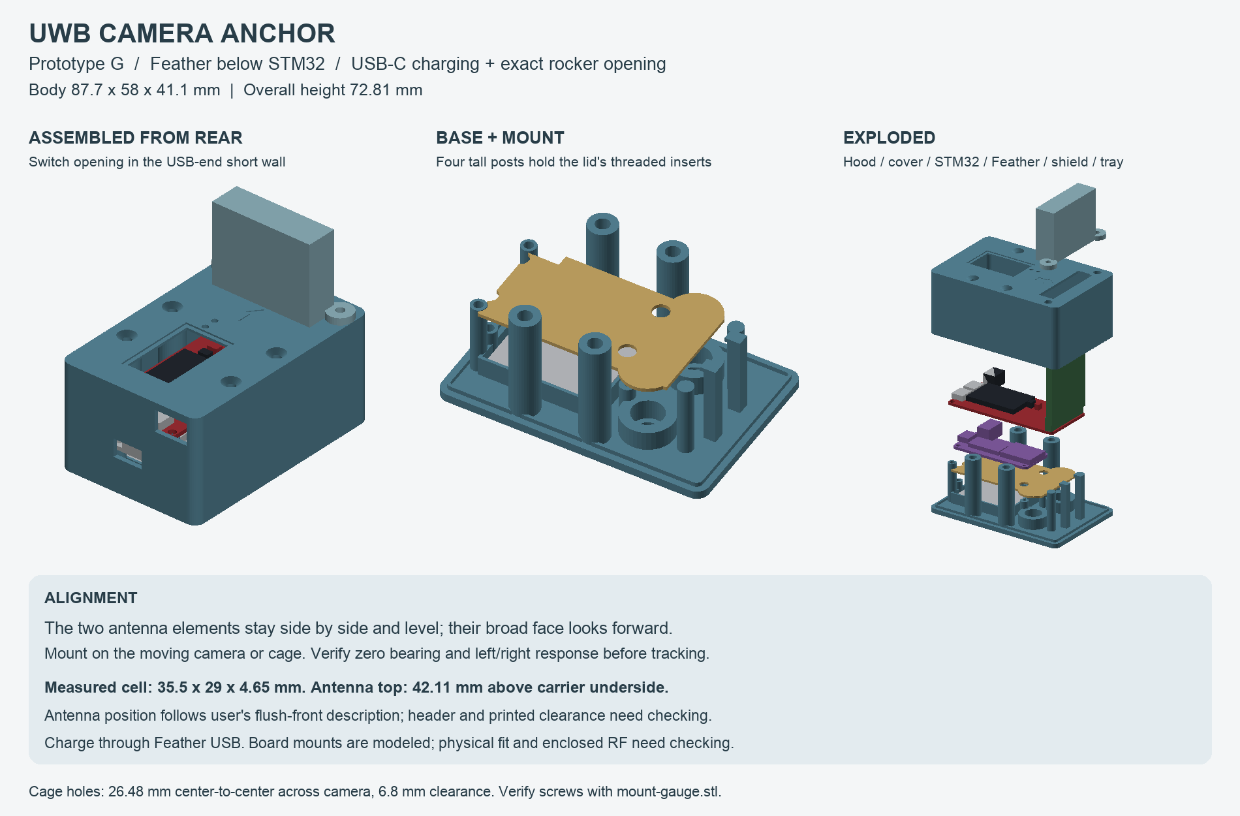
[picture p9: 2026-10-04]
design/mauwb-anchor/preview.png

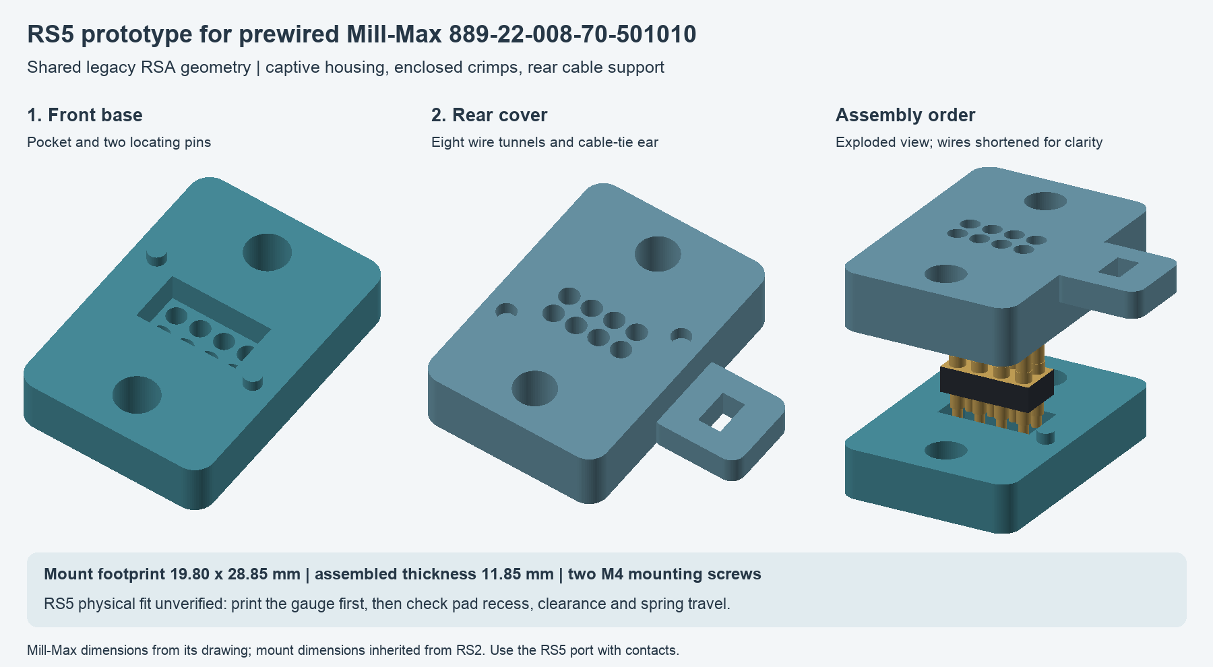
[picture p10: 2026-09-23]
design/carrier-preview.png

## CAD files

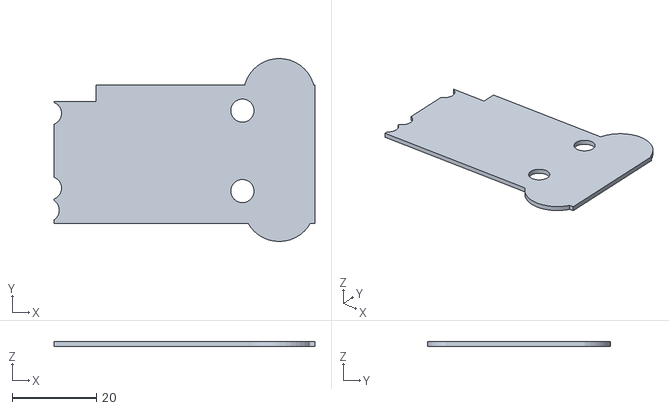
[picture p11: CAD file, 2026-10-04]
design/mauwb-anchor/shield.stl
62.0 x 43.5 x 1.20

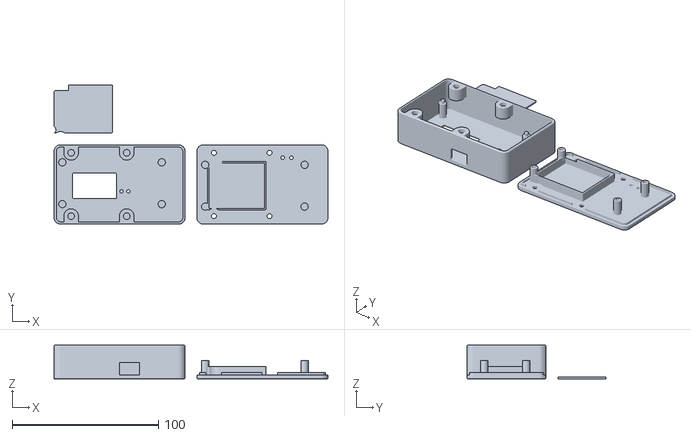
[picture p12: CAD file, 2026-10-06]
design/mauwb-tag/print-plate.stl
187.4 x 95.3 x 23.2

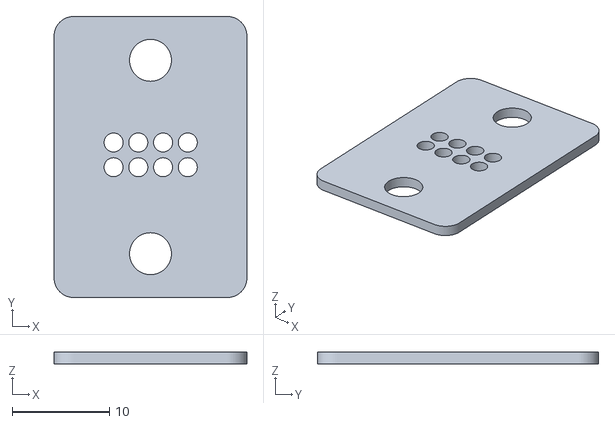
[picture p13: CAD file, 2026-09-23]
design/rs5-fit-gauge.stl
19.8 x 28.9 x 1.20

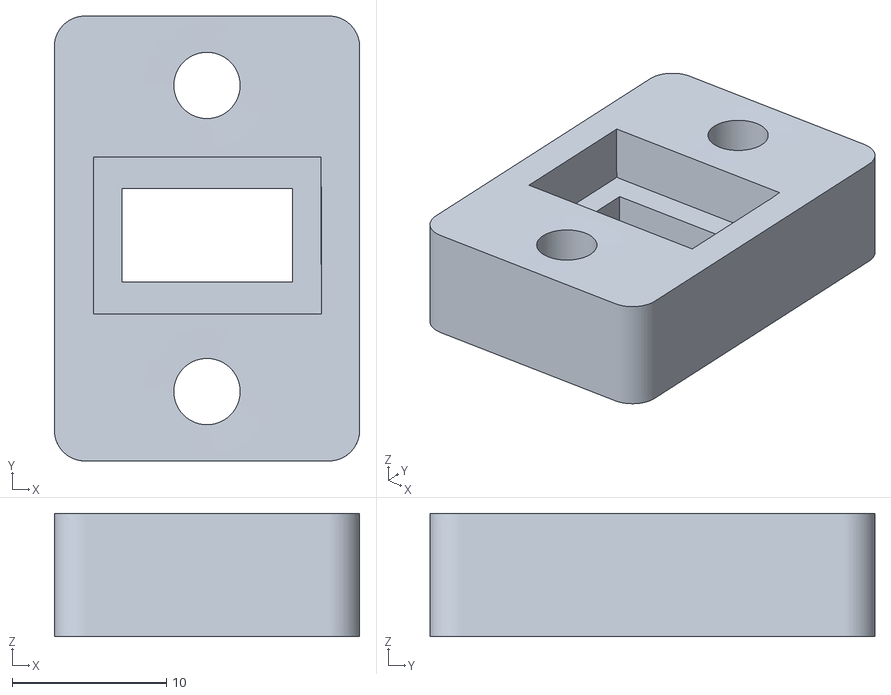
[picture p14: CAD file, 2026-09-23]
references/rileyharmon-rs2-connector.stl
19.8 x 28.9 x 8.00

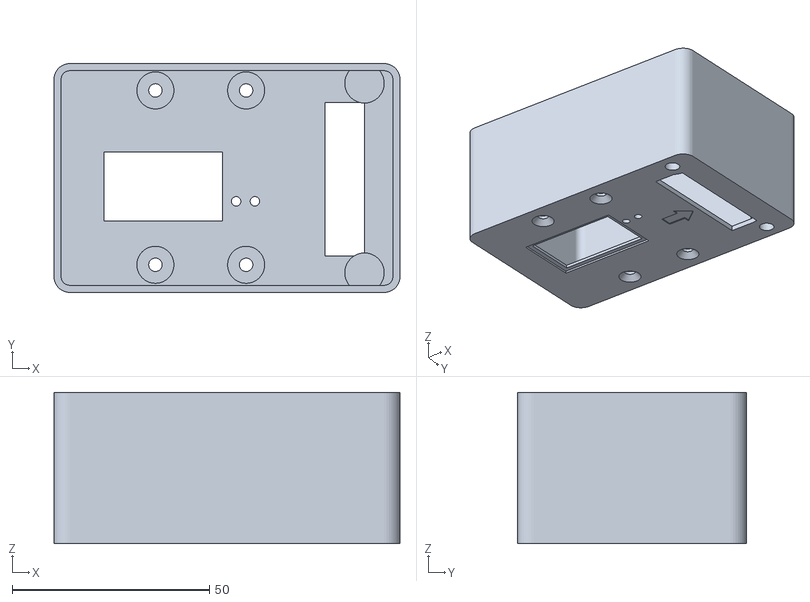
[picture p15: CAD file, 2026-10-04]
design/mauwb-anchor/cover.stl
87.7 x 58.0 x 38.3

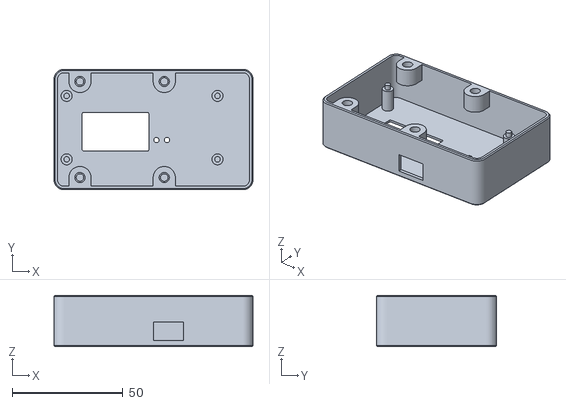
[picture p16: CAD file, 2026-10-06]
design/mauwb-tag/front.stl
89.7 x 54.3 x 23.1

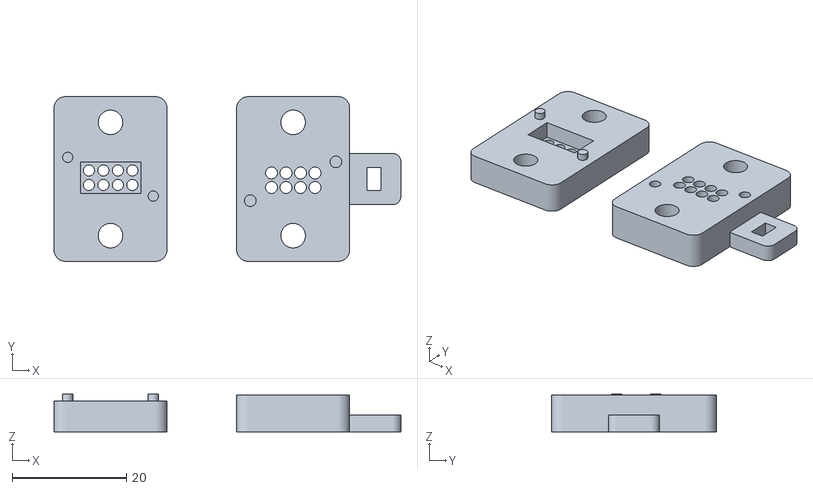
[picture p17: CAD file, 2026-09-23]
design/rs2-millmax-print-plate.stl
60.8 x 28.9 x 6.62

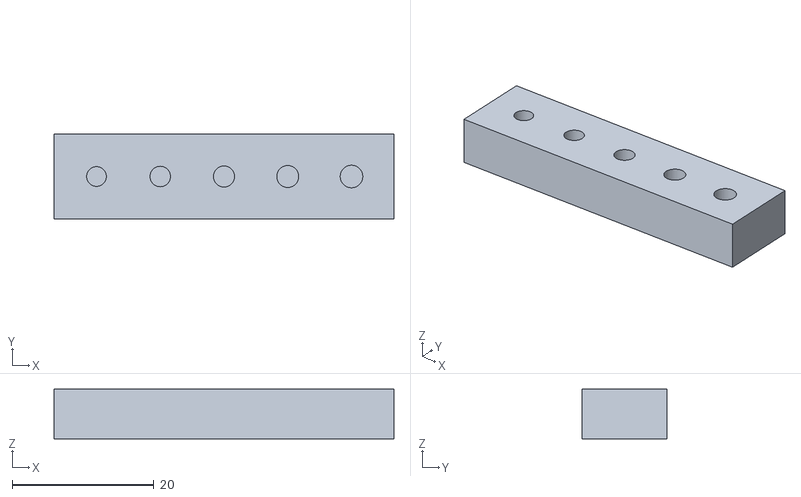
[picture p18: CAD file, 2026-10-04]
design/mauwb-anchor/board-insert-coupon.stl
48.0 x 12.0 x 7.00

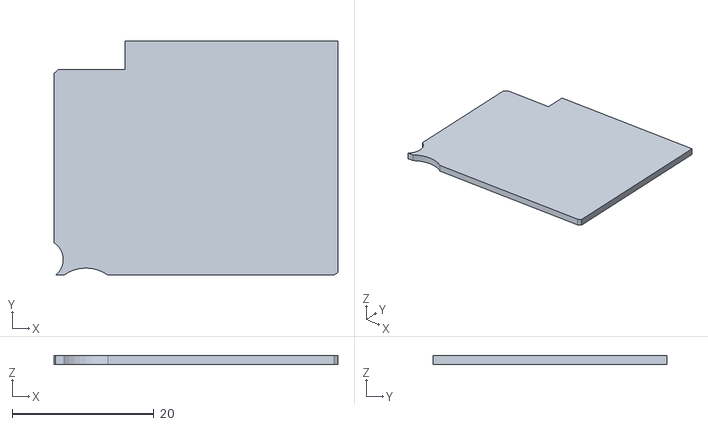
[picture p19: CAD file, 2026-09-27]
design/mauwb-tag/shield.stl
40.0 x 33.0 x 1.20

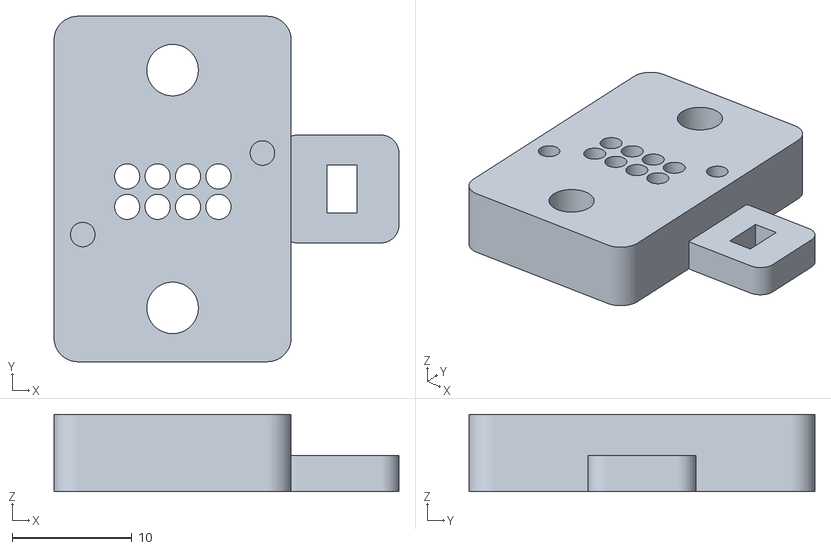
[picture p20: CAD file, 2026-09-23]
design/rs2-millmax-cover.stl
28.8 x 28.9 x 6.43

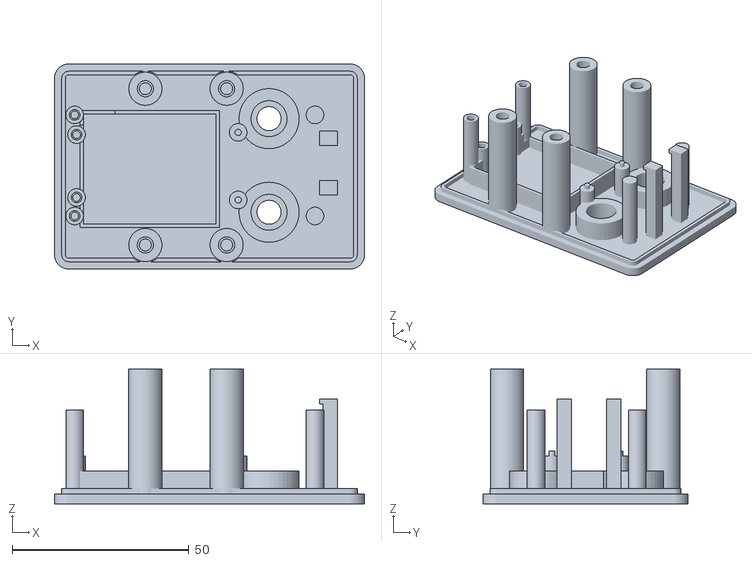
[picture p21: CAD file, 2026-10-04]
design/mauwb-anchor/base.stl
87.7 x 58.0 x 38.1

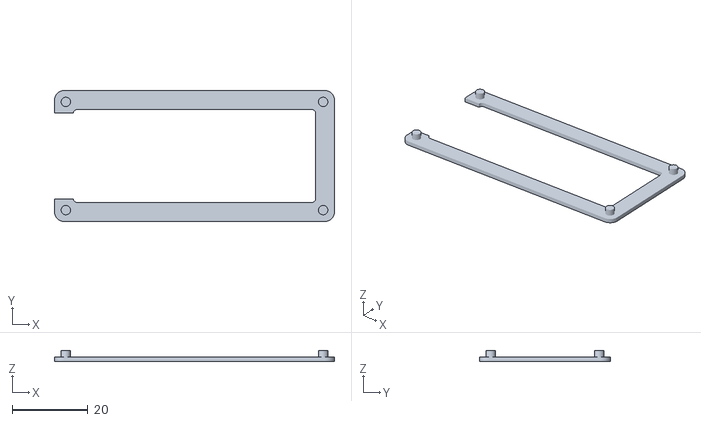
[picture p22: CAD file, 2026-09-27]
design/mauwb-tag/fit-gauge.stl
74.0 x 34.6 x 3.00

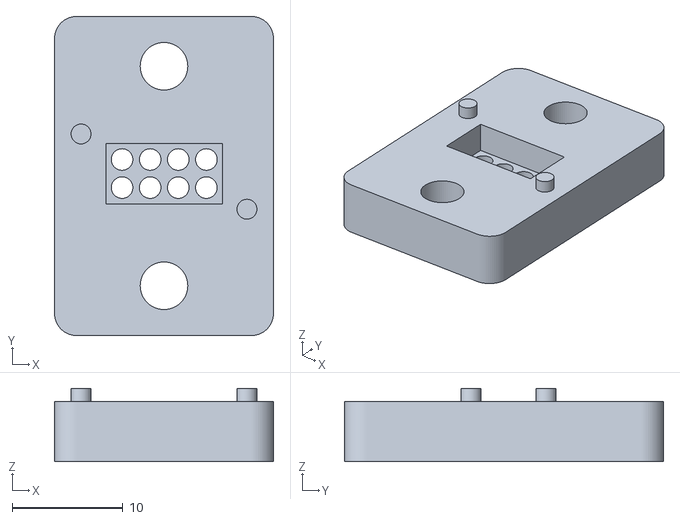
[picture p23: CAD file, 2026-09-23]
design/rs2-millmax-base.stl
19.8 x 28.9 x 6.62

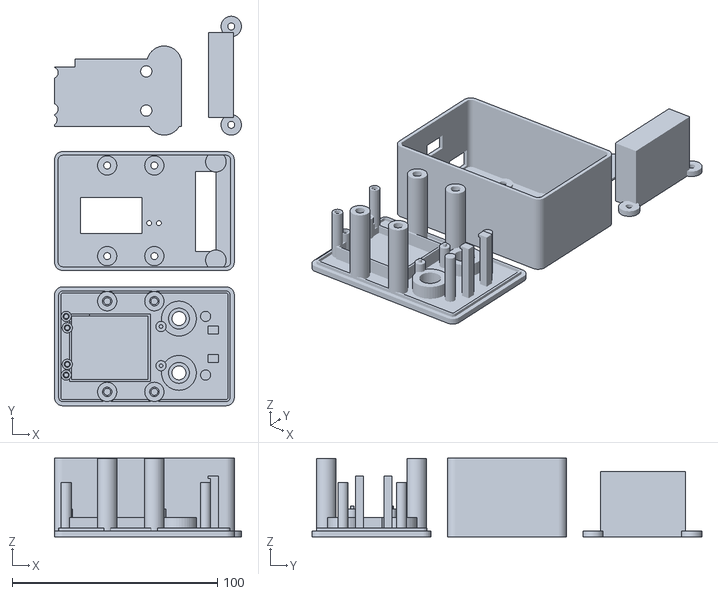
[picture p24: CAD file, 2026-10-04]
design/mauwb-anchor/print-plate.stl
91.2 x 190.0 x 38.3

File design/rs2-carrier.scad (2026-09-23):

// Current design: Mill-Max prewired connector, revision B.
// Edit rsa-millmax.scad for dimensions and output options.
include <rs2-millmax.scad>

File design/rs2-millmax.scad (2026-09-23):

// RS2 entry point. Default holder geometry is unchanged from revision B.
// Edit shared dimensions in rsa-millmax.scad, or override with OpenSCAD -D.
gimbal_model = "RS2";
include <rsa-millmax.scad>

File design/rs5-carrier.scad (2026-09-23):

// Convenience alias for the current RS5 Mill-Max prototype.
include <rs5-millmax.scad>

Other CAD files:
design/mauwb-tag/rear.stl
design/rs5-millmax-base.stl
design/mauwb-anchor/switch-coupon.stl
design/mauwb-tag/insert-coupon.stl
design/rs5-millmax.scad
design/archive/rs2-precidip-rev-a.scad
design/archive/rs2-precidip-rev-a.stl
design/mauwb-anchor/enclosure.scad
design/mauwb-anchor/fit-gauge.stl
design/mauwb-anchor/hood.stl
design/mauwb-anchor/insert-coupon.stl
design/mauwb-anchor/mount-gauge.stl
design/mauwb-tag/enclosure.scad
design/rs5-carrier.stl
design/rs5-millmax-cover.stl
design/rs5-millmax-print-plate.stl
design/rsa-millmax.scad

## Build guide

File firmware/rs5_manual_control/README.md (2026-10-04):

# RS5 manual pan/tilt and UWB follow firmware

For the cable-free moving camera, use the [wireless body build](../rs5_wireless_control/README.md) of this controller and the [camera radio/shared-battery setup](../WIRELESS_UWB.md). This sketch remains the direct-UART build.

Companion to the [local mouse / PS4 UI](../../control_ui/README.md), with X-to-toggle Makerfabs UWB pan follow. [Wiring, first setup, and controls](../../control_ui/UWB_SETUP.md). Exact board: **Adafruit Feather ESP32-S3 8 MB / No PSRAM**. Existing verified wiring remains GPIO5 → Waveshare TX, GPIO6 → RX, 3.3 V supply, shared ground, and CAN H/L to the RS5. Accessory VCC stays insulated.

**Hardware status, updated 2026-10-04:** the user confirmed that the direct `anchor → ESP32 → Waveshare → Mill-Max harness → RS5` setup successfully tracked the tag. The wired interface and following are validated on that setup; the added two-ESP32 wireless path needs its own hardware check.

```sh
arduino-cli compile --fqbn esp32:esp32:adafruit_feather_esp32s3_nopsram --warnings all --build-path "$PWD/tmp/firmware-build-manual" --output-dir "$PWD/tmp/firmware-manual" firmware/rs5_manual_control
arduino-cli upload --fqbn esp32:esp32:adafruit_feather_esp32s3_nopsram --port YOUR_FEATHER_PORT --input-dir "$PWD/tmp/firmware-manual" firmware/rs5_manual_control
```

Boots **disarmed**, in normal 1 Mbit/s Classical CAN mode. No application transmission until `probe`. Speed requests use the documented SDK command 0x0E/0x01 on CAN 0x223; matching joint-angle queries reply on 0x222. Roll speed is always zero. The copied protocol implementation adds pitch encoding at SDK payload bytes 4–5 and retains the existing CRC/parser code.

Manual control caps each controlled axis at **60°/s**. UWB follow caps yaw independently at **30°/s**, initially **5°/s**, with zero pitch/roll speeds. Anchor TXD1/PA9 connects to RX/GPIO38 at 115200 8N1, plus common ground; TX/GPIO39 stays unconnected. The parser and tracker are shared through `firmware/shared`, so retain the repository layout when building. It expires input after 300 ms, telemetry after 400 ms, and stops on USB loss, main-loop stalls, or invalid input. It imposes no starting-angle, absolute-angle, or per-enable travel restrictions. Pan wraparound does not stop movement; joint feedback accepts the SDK’s signed 16-bit range without the old ±180° rejection. See the UI README for physical travel and broken-link limitations. It never automatically resumes after a stop/fault.

## Serial protocol v2 with optional UWB capability

115200 baud, ASCII newline-delimited commands. JSON status is emitted every 50 ms when USB is open, including `protocol:2`, `max_speed_dps:60`, `bounded_retry:true`, device `clock`, session `token`, `armed`, `ready`, live angles, requested speeds, counters, and stop reason. CAN fault telemetry preserves `tx_failed`, `arbitration_lost`, and `fault_alerts` plus the actual reason/counters after driver shutdown.

- `probe`: disable movement and begin read-only joint queries.
- `arm TOKEN CLOCK`: require current token, a device timestamp no more than 300 ms old, three consecutive valid joint replies, fresh telemetry, USB connection, and finite joint angles. Starts at zero speed.
- `drive TOKEN CLOCK SEQ PAN TILT`: request signed speeds in **tenths of a degree/second**; each must be within ±600. SEQ must strictly increase within the enable session. Requires an unexpired input lease. No roll input is exposed.
- `uwb TOKEN CLOCK TAG SIGN ZERO MAX`: disarm and configure UWB. TAG is a decimal unsigned 16-bit short address (the UI accepts four hex digits); SIGN is +1 or −1; ZERO is center offset in tenths of a degree within ±300; MAX is tenths of °/s from 10–300. Reacquire three reports after applying. Settings are volatile.
- `track TOKEN CLOCK`: arm follow only with configured/fresh selected-tag data and the same joint/USB prerequisites as manual arm. Start the tracking ramp from rest.
- `follow TOKEN CLOCK SEQ`: refresh the follow input lease with a strictly increasing sequence, no supplied speeds. It cannot start an inactive session. `drive` is rejected during follow and `follow` is rejected during manual control.
- `stop`: zero/release if active, invalidate the enable session; retain telemetry queries.
- `idle`: stop and end queries, used when disconnecting.
- `status`, `help`: diagnostic output only.

The JSON `uwb` object advertises support and reports `configured`, selected `tag`, recent `observed`/`observed_tag`, fix `fresh`, `following`, `bearing`, `range_m`, `age_ms`, report/error counters, direction, center, maximum speed, and fix reason. A field alone never enables motion. Invalid UWB input only stops an active follow session; it does not disable manual control.

Each stop rotates the session token. Delayed, malformed, replayed, or out-of-range input stops active motion. Expiry is checked before buffered serial input can refresh the lease. Packet transmission uses normal CAN arbitration retries within a 20 ms deadline; no application backlog is replayed. CAN faults stop/uninstall the driver and clear pending frames; physical disconnection can prevent any stop request from reaching the gimbal.

## Combined build validation — 2026-09-29

The combined build compiles for the exact Feather board with Arduino-ESP32 3.3.11: **382,766 bytes flash** and **59,688 bytes static RAM**. Sanitized tests exercise the actual sketch with framed UART data and simulated CAN, including follow leases, tag loss, replay, parser errors, UART overrun, loop stalls, USB/joint loss, direction/speed limits, and manual fallback. Python/JavaScript integration checks cover UI and bridge behavior. See the [full setup and validation](../../control_ui/UWB_SETUP.md).

Flashed and hash-verified on the connected Feather on **2026-09-29**, using `/dev/cu.usbmodem101`. The actual-sketch UWB and manual transport tests passed again before upload. An eight-second passive USB check captured 160 status samples and **280 incoming UWB reports from tag `0E4C`**, with zero UWB parsing errors and zero sampled CAN error counters. The device advertised protocol 2, UWB support, 60°/s manual maximum and 5°/s initial follow maximum. It remained disarmed, unconfigured and at zero requested speeds throughout. No serial commands, CAN queries or motion commands were sent during this check; that check did not test steering direction or physical following. The user's later wired tracking confirmation is recorded above. Logs: `tmp/rs5-ui-uwb-flash-check.jsonl` and `tmp/rs5-ui-uwb-flash-summary.json` (includes application SHA-256). The anchor and tag retain their factory firmware. Select/apply the intended tag in the UI before following; it is not automatically selected by this verification.

## Earlier manual-only validation

The earlier 60°/s build uses Arduino-ESP32 3.3.11 for the exact Feather profile: **363,786 bytes flash** and **59,008 bytes static RAM**. Only the existing Arduino/TinyUF2 macro-name warnings appeared. Device-side speed/timeout tests pass under address and undefined-behavior sanitizers, including timer wrap, malformed/replayed input, full-speed signed encoding, three simulated uninterrupted pan revolutions, reverse wraparound, and telemetry beyond ±180°. The independent DJI SDK framing vector and pitch-byte ordering are checked. USB read-only verification is recorded separately; 60°/s and full-turn movement require the operator’s hands-on check.

Flashed and hash-verified on 2026-09-28. The UI bridge received 15 valid joint replies while disarmed, with zero requested speeds and zero sampled bus errors / receive loss / REC / TEC. See the [UI hardware result](../../control_ui/README.md#hardware-check--2026-09-28). No new motion was sent during this verification. The UI now opens this internal control session automatically for a fresh held mouse control or L1 gesture and closes it on release; no manual enable/stop buttons are needed.

After the 60°/s update, upload/hash verification and the read-only check passed again. The board reported `protocol:2`, `max_speed_dps:60`, 15 valid replies, and all error counters zero while disarmed. Log: `tmp/rs5-ui-60dps-check.jsonl`.

The former single-shot flag could turn ordinary arbitration loss into TX failure. Tests of the actual sketch using a fake TWAI driver verify arbitration can complete within the packet deadline, persistent TX is cleared after 20 ms, and fault details survive shutdown and subsequent stop commands. USB disconnection also ends telemetry queries. These changes preserve the existing input/telemetry watchdogs.

The earlier retry build was flashed and hash-verified. A 90-second read-only check returned 900 joint replies with zero errors/loss/TX failures/REC/TEC while disarmed. The board advertised `bounded_retry:true`. No arbitration-loss events occurred in the observed window, and motion was not commanded. See the UI README for the log and exact test scope.

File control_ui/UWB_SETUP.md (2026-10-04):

# UWB follow in RS5 Control Desk

**Wireless camera connection:** the [two-Feather electronics revision](../firmware/WIRELESS_UWB.md) replaces the moving-camera UART cable with ESP-NOW and powers the camera-side anchor/Feather from one 500 mAh cell. Use `rs5_anchor_radio` on the camera and `rs5_wireless_control` on the body. Pair/build instructions and shared-battery wiring are in that guide; the controls below also apply. The direct UART wiring and build commands below remain the original wired option.

**Hardware status, updated 2026-10-04:** the user confirmed successful tag tracking through `anchor → ESP32 → Waveshare → Mill-Max pin harness → RS5`. The wired interface and following have been validated on that setup. The new ESP-NOW hop still needs pairing and a physical follow test; use the [flashing instructions for both ESP32s](../README.md#flash-both-esp32s).

Use the existing **rs5_manual_control** Feather application for both mouse/PS4 control and Makerfabs UWB follow. The original MaUWB_STM32 AoA kit keeps its factory anchor/tag firmware. The Feather reads the anchor's UART reports and generates DJI speed packets over the already working CAN connection. The separate `rs5_uwb_tracker` sketch remains a console-only prototype; it is not the UI firmware.

## Connection layout

```mermaid
flowchart LR
    PS4[PS4 controller] -->|USB or Bluetooth| Mac[Mac: Control Desk]
    Mac -->|USB: mode and live input lease| Feather[Feather ESP32-S3]
    Tag[Tag carried by subject] -. UWB .-> Anchor[Anchor mounted on moving camera]
    Anchor -->|TXD1 → RX/GPIO38: 3.3 V UART| Feather
    Feather -->|GPIO5 TX / GPIO6 RX| CAN[Waveshare SN65HVD230]
    CAN -->|CANH / CANL: 1 Mbit/s| RS5[RS5 verified RSA connection]
```

| From | To | Notes |
| --- | --- | --- |
| Anchor **TXD1 / PA9**, J2 pin 4 | Feather **RX / GPIO38** | New wire; 3.3 V UART, 115200 baud, 8N1 |
| Anchor **GND**, J2 pin 2 | Feather **GND** | New shared signal ground |
| Feather **5 / GPIO5** | Waveshare **TX** | Existing connection |
| Feather **6 / GPIO6** | Waveshare **RX** | Existing connection |
| Feather **3V** | Waveshare **3.3V** | Existing breakout power |
| Feather **GND** | Waveshare **GND** and verified RS5 **GND** | Existing connection |
| Waveshare **CANH / CANL** | Verified RS5 **CANH / CANL** | Keep the proven termination and detect-resistor arrangement |

J2 numbers refer to the vendor **V1.1 schematic**, not a pin count from an arbitrary viewing angle. Identify the pads by silkscreen and confirm your board revision. Anchor TXD1 also feeds the onboard CH340 receive input; this additional receiver is connected in parallel. Leave **Feather TX/GPIO39 unconnected**. Do not connect it to anchor RXD1/PA10, which is already driven by the CH340. Power down before wiring.

Power the anchor and Feather through separate USB connections with common ground. Power the tag through USB-TTL or its supported battery. Leave their 3.3 V/5 V supply rails separate and RS5 accessory VCC insulated. For the existing RS5 contact layout, see the [main wiring table](../README.md#electrical-design).

Mount the anchor on the **moving camera platform**, aligned with the lens so it turns toward the tag as the camera pans. Keep its angle measurement plane horizontal and the camera approximately level. Rebalance the camera and provide cable clearance. This controller cannot use a fixed handle-mounted anchor without an additional coordinate transform. The original kit supplies one angular dimension, so follow changes **pan only**; pitch and roll requested speeds are zero. It does not estimate subject height or perform a 360° tag search.

## Prepare the anchor and tag

1. Connect the anchor's **USB-NATIVE** port to the computer and power the tag. Use Makerfabs **AOA System** to discover and bind **one tag**. Multiple saved tag bindings can prevent valid reports.
2. Verify the kit displays changing distance and position. Use JSON output. On the anchor's USB-NATIVE serial port at 115200 with CR+LF, `USER_CMD 0` selects JSON and `SAVE` persists it. `GETKLIST` shows bindings and the four-digit `a16` short tag ID. [Full factory setup and binding commands](../firmware/rs5_uwb_tracker/README.md#prepare-the-makerfabs-kit).
3. Connect TXD1 and GND to the Feather as above. The UI shows **Receiving tag HHHH** when framed UART measurements arrive. The ID is never automatically selected for control. Enter the short ID belonging to your tag, not its 64-bit radio address.

The receiver follows the Makerfabs `JS` + four hexadecimal length digits + JSON framing. It uses `D`, `Xcm`, `Ycm` and the ranging sequence `R`; raw phase `P` is not treated as a bearing. No STM32 source changes or ST-Link flashing are required for this path.

## Build and run

Build the combined firmware for the exact Feather profile. Keep the full repository directory layout, including `firmware/shared`:

```sh
arduino-cli compile \
  --fqbn esp32:esp32:adafruit_feather_esp32s3_nopsram \
  --warnings all \
  --build-path "$PWD/tmp/firmware-build-manual" \
  --output-dir "$PWD/tmp/firmware-manual" \
  firmware/rs5_manual_control
arduino-cli board list
```

Close the UI's serial connection before uploading, then use the **Feather's port**, not the Makerfabs port:

```sh
arduino-cli upload \
  --fqbn esp32:esp32:adafruit_feather_esp32s3_nopsram \
  --port YOUR_FEATHER_PORT \
  --input-dir "$PWD/tmp/firmware-manual" \
  firmware/rs5_manual_control
python3 control_ui/server.py
```

Open **http://127.0.0.1:8765**, choose the Feather, connect, and wait for LIVE RS5 angles. Release mouse/L1/X once after connecting. Firmware boots disarmed; neither connecting nor applying settings starts follow.

In **UWB FOLLOW**, enter your tag ID, use **5°/s**, direction **Normal (+)**, center offset **0°**, and click **Apply UWB settings**. Wait for **TAG LIVE**. Settings are acknowledged by device telemetry and cleared by a Feather reset; the browser does not silently restore or select a target. After a page reload, enter/apply the desired settings again before following. Old manual-only firmware still works for manual motion, but the UWB panel requests a firmware update.

No-hardware preview:

```sh
python3 control_ui/server.py --demo --port 8766
```

Open **http://127.0.0.1:8766**, connect to the simulated Feather, and apply tag **1234**. The PREVIEW MODE banner stays visible. The simulator never opens USB or CAN.

## Controls and first follow test

| Input | Behavior |
| --- | --- |
| **PS4 X / Cross** (standard mapping button 0) | Toggle UWB follow on/off; one action per press |
| **Start/Stop UWB follow** in the panel | Same toggle using the mouse |
| **Circle**, **Space**, **Escape** | Stop all motion |
| **L1** or mouse pad/direction control during follow | Cancel follow; release and hold again for manual motion |
| **L1 + left stick** outside follow | Existing analog manual pan/tilt; release L1 to stop |
| Changing settings, leaving the page, controller loss, connection loss | Stop; a fresh action is required to restart |

Place the tag 2–5 m in front of the lens, at approximately anchor height. Check bearing and distance before starting. With the tag slightly off center, press X briefly and then press X again to stop. The camera should turn **toward** the tag and bearing magnitude should decrease. If it turns away, stop, choose **Reverse (−)**, apply settings, and repeat. The manual-control Reverse pan setting does not change this independent follow direction. Verify both sides; the earlier observation that positive DJI yaw speed decreases reported joint yaw does not establish the sign of an installed UWB sensor.

To compensate a consistent mounting offset, put the tag at the desired lens center and enter its displayed bearing as **Center offset**, then apply. This is an angular offset, not multipath correction. Check tag power loss stops follow and bringing the tag back does not restart it; press X again after TAG LIVE. A single anchor has a limited field of view. Use manual control to reacquire a lost tag before restarting.

## Tracking behavior

The device calculates bearing as `atan2(Xcm, Ycm)`, smooths it with a 0.25 s time constant, applies a 3° deadband, and limits acceleration to 45°/s². Follow speed is independently configurable from **1–30°/s**, initially **5°/s**. Manual maximum remains **60°/s**. Valid fixes require three selected-tag reports, 0.75–20 m distance, positive forward coordinate, and bearing within ±55°. An angular jump above 25°, malformed/incomplete input, or UART overrun invalidates the fix. Duplicate/recent out-of-order ranging sequences and reports from other tags cannot refresh it. The parser/control core is shared with the console prototype in `firmware/shared`.

The former 15°/s UI limit was a conservative bench-test setting, not a measured RS5 maximum. **The UI and body firmware now accept up to 30°/s.** Rebuild/reflash the body using `rs5_wireless_control` (or `rs5_manual_control` for wired UART), restart the Control Desk server and reload the page; older body firmware rejects settings above 15°/s. The camera relay needs no update for this limit change; retain the existing pairing configuration when rebuilding. Stop follow, set **Follow limit (°/s)**, click **Apply UWB settings**, wait for TAG LIVE, then start again. This is a speed ceiling: smaller bearing errors still produce slower motion with the existing gain, smoothing and acceleration. The separate console prototype retains its 15°/s default.

Tag freshness expires after **300 ms**. Follow also requires fresh browser input at about 20 Hz, a 250 ms bridge lease, the device's 300 ms input lease, and joint telemetry within 400 ms. Each heartbeat authorizes continued device-side tracking; it contains no host-computed speed. There is no generated heartbeat from cached browser intent. Timeouts are checked before buffered commands and UWB reports can revive old state. Tag loss disarms and invalidates the session; fresh tag reports alone never re-arm it. No extra joint-angle travel restrictions are added to the working manual firmware.

Normal cancellation sends zero speed then releases SDK control. CAN faults retain the existing 20 ms bounded transmit deadline, clear queued transmission, stop the CAN driver, and require a Feather reset. A physically broken control link can prevent stop packets from reaching the RS5. Keep the gimbal supported, balanced, clear of cables, and supervised during the first tracking tests. RF quality, mounting alignment, direction, and real stopping behavior require hands-on validation.

## Validation status — 2026-09-29

The combined firmware compiles with Arduino-ESP32 3.3.11 for the Adafruit Feather ESP32-S3 No PSRAM: **382,766 bytes flash, 59,688 bytes static RAM**. The standalone preview still compiles. All 30 Python tests passed. Node input and frontend-event checks and four sanitized C++ test executables passed. Automated checks cover the actual combined sketch with simulated UART/TWAI, the UWB parser and tracking core, existing manual limits/watchdogs, Python bridge and localhost WebSocket lifecycle, and the actual browser JavaScript under an event/DOM fixture. Scenarios include X edge detection, tag loss, stale/replayed leases, no automatic restart, UART errors/backlog, manual fallback, controller/focus/animation loss, and follow calibration/speed limits.

The combined build was **flashed and hash-verified on 2026-09-29**. A passive eight-second USB check captured 160 status samples and 280 incoming UWB reports from tag **`0E4C`**, with zero parsing errors and zero sampled CAN error counters. The Feather remained disarmed, at zero requested speeds, with no tag configured. No commands or CAN queries were sent during verification. Logs: `tmp/rs5-ui-uwb-flash-check.jsonl` and `tmp/rs5-ui-uwb-flash-summary.json`. The anchor/tag factory firmware was retained. That passive check did not test physical following or steering direction. **The user subsequently confirmed working wired tag tracking, reported on 2026-10-04.** Browser visual inspection was unavailable during development because the browser plugin reported no available browser. That software/passive check did not measure RF accuracy; keep the working mount's direction setting when moving to wireless and verify it on the assembled system.

Sources: [Makerfabs original kit repository](https://github.com/Makerfabs/UWB-AOA-with-Display-STM32F103C8T6), locally reviewed at `34b9705edcb7feca83f652280047847d4bc03c34`. The V1.1 schematic defines TXD1/PA9 and GND; `Firmware/stm32cube/CubeIde/projectN/Core/Src/usart.c` sets 115200, `APP/Generic_cmd.c` mirrors output to UART, and `DW/PDoA/json_2pc.c` defines the measurement framing and fields. Makerfabs advertises ±60° coverage and ±5° angular error; the narrower ±55° acceptance here is a controller setting, not a measured guarantee.

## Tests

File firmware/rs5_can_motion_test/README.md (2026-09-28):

# Finite RS5 motion bench test

Adafruit Feather ESP32-S3 8 MB/no PSRAM; the same verified Waveshare wiring as the CAN monitors: GPIO5 to CAN TX, GPIO6 to CAN RX, 3V to 3.3V, shared ground, and RS5 H/L to CANH/CANL. No UWB kit is required.

The sketch boots in normal CAN mode, acknowledging frames but sending no application messages. `probe` enables documented joint-angle queries on CAN ID 0x223. Replies on 0x222 must match the query sequence, both CRCs, command, successful return code, joint-angle type, and angle bounds. It must receive three consecutive valid replies before allowing `run`.

`run` performs exactly three cycles: positive yaw speed 5 degrees/s for one second, zero speed for two seconds, negative yaw speed 5 degrees/s for one second, zero speed for two seconds. Left/right sign depends on the installation and viewing direction. Roll and pitch requested speeds are zero. Speed requests repeat every 50 ms; the final action sends zero speed and releases control. It does not change stored gimbal modes or limits.

The unit must be balanced, supported, unlocked for normal operation, and clear of cable/physical obstructions, with the physical power control accessible. These are supervised first-motion tests. The 0.5-second speed-command expiration is specified in the older DJI SDK; software cannot guarantee a stop if the link or device fails.

Motion aborts on telemetry older than 400 ms, host heartbeat loss for 750 ms, USB disconnect, a loop stall over 100 ms, invalid console input, or a joint-angle excursion over 8 degrees from initial yaw / 5 degrees from initial roll or pitch. Initial yaw must be inside +/-70 degrees and active yaw inside +/-80 degrees. Faults never automatically restart motion. A usable bus receives zero/release on abort; a CAN fault stops the driver and clears TX, and may prevent a stop packet from reaching the gimbal.

## Build and flash

```sh
arduino-cli compile --fqbn esp32:esp32:adafruit_feather_esp32s3_nopsram --warnings all --build-path "$PWD/tmp/firmware-build-motion-test" --output-dir "$PWD/tmp/firmware-motion-test" firmware/rs5_can_motion_test
arduino-cli upload --fqbn esp32:esp32:adafruit_feather_esp32s3_nopsram --port YOUR_PORT --input-dir "$PWD/tmp/firmware-motion-test" firmware/rs5_can_motion_test
```

## Run

Close other serial monitors. The Python helper requires pyserial and logs all console output. Without `--run`, it verifies joint queries only. Add `--run` only when ready for the fixed motion test. It maintains the heartbeat, never retries `run`, and sends `stop` on completion, timeout, or interruption.

```sh
python3 firmware/rs5_can_motion_test/run_test.py --port YOUR_PORT --log tmp/rs5-joint-check.log
python3 firmware/rs5_can_motion_test/run_test.py --port YOUR_PORT --run --log tmp/rs5-motion-test.log
```

Console commands, each followed by newline: `help`, `status`, `probe`, `ping`, `run`, `stop`. Send `ping` at least every 200 ms while running; otherwise the firmware aborts within 750 ms. `stop` ends motion and queries. The host helper sends it before closing the port. Closing USB during motion also triggers abort. The board remains in normal CAN mode while idle; reflash the passive monitor to restore listen-only operation.

## Checks

```sh
c++ -std=c++17 -Wall -Wextra -Werror -fsanitize=address,undefined -fno-omit-frame-pointer firmware/tests/motion_sequence_test.cpp -o tmp/motion_sequence_test
tmp/motion_sequence_test
```

The sequence checks cover all three cycles and pauses, timer wrap, operator stop, stale telemetry, heartbeat loss, loop stalls, nonfinite angles, and the excursion limits. Packet encoding/parser code is copied from the existing tracker and checked against the independent DJI SDK vector in `firmware/tests/tracker_test.cpp`.

## Hardware result — 2026-09-28

Compiled for the exact Feather profile with Arduino-ESP32 3.3.11: 363,458 bytes of application flash and 58,896 bytes of static RAM. Upload and flash verification passed. The motion-sequence and existing tracker/protocol host tests passed with address/undefined-behavior sanitizers. The Arduino core emitted its existing TinyUF2 partition macro warning.

After the operator confirmed the balanced, stabilized gimbal was ready, the host helper ran all three requested cycles. Joint yaw started at 1.9 degrees, ranged from -3.2 to +2.2 degrees in the sampled telemetry, and ended at 2.2 degrees. Pauses showed steady joint angles, and the run ended with `DONE reason=completed zero_and_release_sent=yes`. All sampled bus-error, receive-loss, REC and TEC counters were zero. There were 196 validated joint replies before the host stopped queries and closed the port. The flashed sketch remains idle, with no automatic restart.

**On this unit, positive requested yaw speed decreased the reported joint yaw; negative speed increased it.** Do not assume speed-command sign matches joint-angle sign when building a closed-loop controller. Camera left/right still depends on viewing orientation.

Local logs (ignored by Git): `tmp/rs5-query-check-20260928.log` records the initial read-only tracker probe, and `tmp/rs5-motion-test-20260928.log` records this finite test. This validates the tested joint queries, small yaw motions, pauses, and normal completion. The fault-abort cases were host-tested, not physically injected; a broken-link stop and the SDK's 0.5-second fallback remain unverified on hardware.

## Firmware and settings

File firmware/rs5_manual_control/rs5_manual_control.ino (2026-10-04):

// Local UI manual pan/tilt and Makerfabs UWB pan follow. Boots disarmed.
// Firmware leases and telemetry guards remain authoritative if the host fails.
#include <Arduino.h>
#include <driver/gpio.h>
#include <driver/twai.h>
#include <esp_err.h>
#include <inttypes.h>
#include <stdarg.h>
#include <esp_random.h>
#include <stdlib.h>
#include <errno.h>
#include "ConsoleQueue.h"
#include "DjiProtocol.h"
#include "ManualControl.h"
#include "TrackingCore.h"

#ifndef RS5_UWB_WIRELESS
#define RS5_UWB_WIRELESS 0
#endif
#if RS5_UWB_WIRELESS
#include "../shared/EspNowLink.h"
static wireless::Receiver radioReceiver;
static uint32_t lastPollMs = 0;
#endif

#if !defined(CONFIG_IDF_TARGET_ESP32S3)
#error "Select the Adafruit Feather ESP32-S3 No PSRAM board."
#endif

static constexpr gpio_num_t CanTx = GPIO_NUM_5, CanRx = GPIO_NUM_6;
static constexpr uint32_t QueryMs = 100, JointTimeoutMs = 400;
static constexpr uint32_t FaultAlerts = TWAI_ALERT_BUS_ERROR | TWAI_ALERT_BUS_OFF |
    TWAI_ALERT_RX_QUEUE_FULL | TWAI_ALERT_RX_FIFO_OVERRUN | TWAI_ALERT_TX_FAILED;
static bool canReady = false, probing = false, queryPending = false, haveJoint = false;
static uint16_t sequence = 0, querySequence = 0;
static uint32_t querySentMs = 0, jointMs = 0, lastControlMs = 0, lastReportMs = 0;
static uint32_t received = 0, validReplies = 0, consecutiveReplies = 0, skippedLogs = 0;
static dji::JointAngles joint;
static dji::StreamParser parser;
static ManualControl motion;
static tracking::Tracker tracker;
#if !RS5_UWB_WIRELESS
static uwb::StreamParser uwbParser;
#endif
static bool following = false, uwbConfigured = false, haveObservedTag = false;
static int uwbDirection = 1, uwbZero = 0, uwbMaxSpeed = 50;
static int16_t outputPan = 0, outputTilt = 0;
static uint16_t observedTag = 0;
static uint32_t uwbReports = 0, uwbBad = 0, observedMs = 0, lastLoopMs = 0;
#if !RS5_UWB_WIRELESS
static volatile bool uartError = false;
#endif
static uint32_t sessionToken = 0;
static twai_status_info_t lastCanStatus = {};
static uint32_t faultAlerts = 0;
static const char *faultReason = "none";
static ConsoleQueue<4096> console;
static char command[128];
static size_t commandLength = 0;
static bool badCommand = false;

static void logLine(const char *format, ...) {
  char line[1280];
  va_list args;
  va_start(args, format);
  const int length = vsnprintf(line, sizeof(line), format, args);
  va_end(args);
  if (length <= 0 || length >= static_cast<int>(sizeof(line)) || !Serial ||
      !console.append(line, static_cast<size_t>(length))) ++skippedLogs;
}
static void drainConsole() {
  if (!Serial || !console.size()) return;
  const int available = Serial.availableForWrite();
  if (available <= 0) return;
  size_t n = console.contiguousSize();
  if (n > static_cast<size_t>(available)) n = available;
  console.consume(Serial.write(console.data(), n));
}
static bool fresh(uint32_t now) { return haveJoint && now - jointMs <= JointTimeoutMs; }

static void canFault(const char *reason, uint32_t alerts = 0) {
  faultReason = reason;
  faultAlerts = alerts;
  if (canReady) twai_get_status_info(&lastCanStatus);
  motion.stop(reason);
  following = false; outputPan = outputTilt = 0;
  sessionToken = esp_random();
  probing = queryPending = haveJoint = false;
  if (canReady) { twai_stop(); twai_driver_uninstall(); }
  canReady = false;
  gpio_set_level(CanTx, 1);
  gpio_set_direction(CanTx, GPIO_MODE_OUTPUT);
  logLine("ABORT CAN fault: %s alerts=0x%08" PRIx32 " tx_failed=%" PRIu32
          " arbitration_lost=%" PRIu32 " bus_errors=%" PRIu32
          ". TX cleared; reset required.\n", reason, alerts, lastCanStatus.tx_failed_count,
          lastCanStatus.arb_lost_count, lastCanStatus.bus_error_count);
}

static bool checkAlerts(uint32_t alerts) {
  if (!(alerts & FaultAlerts)) return true; // Arbitration loss alone is normal CAN.
  const char *reason = alerts & TWAI_ALERT_BUS_OFF ? "can_bus_off" :
      alerts & TWAI_ALERT_TX_FAILED ? "can_transmit_failed" :
      alerts & TWAI_ALERT_BUS_ERROR ? "can_bus_error" :
      alerts & TWAI_ALERT_RX_QUEUE_FULL ? "can_receive_queue_full" : "can_receive_overrun";
  canFault(reason, alerts);
  return false;
}

// Complete one SDK packet before another. Normal CAN arbitration retries are
// allowed within a 20ms packet deadline; expiry stops the driver and clears TX.
static bool sendPacket(const dji::Packet &packet) {
  if (!canReady || !packet.length) return false;
  const uint32_t began = millis();
  for (size_t offset = 0; offset < packet.length; offset += 8) {
    if (millis() - began >= 20) { canFault("transmit completion timeout"); return false; }
    twai_message_t frame = {};
    frame.identifier = dji::TxCanId;
    frame.ss = 0; // Single-shot would also fail on ordinary arbitration loss.
    const size_t remaining = packet.length - offset;
    frame.data_length_code = remaining > 8 ? 8 : remaining;
    memcpy(frame.data, packet.bytes + offset, frame.data_length_code);
    if (twai_transmit(&frame, 0) != ESP_OK) {
      canFault("transmit failed"); return false;
    }
  }
  while (true) {
    uint32_t alerts = 0;
    if (twai_read_alerts(&alerts, 0) == ESP_OK && !checkAlerts(alerts)) return false;
    twai_status_info_t status = {};
    if (twai_get_status_info(&status) != ESP_OK || status.state != TWAI_STATE_RUNNING) {
      canFault("driver state"); return false;
    }
    if (status.msgs_to_tx == 0) return true;
    if (millis() - began >= 20) { canFault("transmit completion timeout"); return false; }
    delay(1);
  }
}

static void stopMotion(const char *reason, bool forceStop = false) {
  const bool wasActive = motion.active() || forceStop;
  motion.stop(reason);
  following = false; outputPan = outputTilt = 0;
  sessionToken = esp_random();
  bool stopped = true;
  if (wasActive) {
    stopped = sendPacket(dji::axisSpeed(++sequence, 0, 0, true));
    if (stopped) stopped = sendPacket(dji::axisSpeed(++sequence, 0, 0, false));
  }
  if (wasActive) logLine("%s reason=%s zero_and_release_sent=%s\n",
      strcmp(reason, "completed") == 0 ? "DONE" : "ABORT", reason, stopped ? "yes" : "no");
}

static void status(uint32_t now) {
  if (canReady) twai_get_status_info(&lastCanStatus);
  const twai_status_info_t &s = lastCanStatus;
  logLine("{\"type\":\"device\",\"protocol\":2,\"max_speed_dps\":%u,\"clock\":%" PRIu32
          ",\"token\":%" PRIu32 ",\"armed\":%s,\"can_ready\":%s,\"fresh\":%s,"
          "\"ready\":%s,\"probing\":%s,\"yaw\":%.1f,\"roll\":%.1f,\"pitch\":%.1f,"
          "\"pan_speed\":%.1f,\"tilt_speed\":%.1f,\"replies\":%" PRIu32 ",\"reason\":\"%s\","
          "\"bus_errors\":%" PRIu32 ",\"rx_missed\":%" PRIu32 ",\"fifo_overrun\":%" PRIu32
          ",\"rec\":%" PRIu32 ",\"tec\":%" PRIu32 ",\"tx_failed\":%" PRIu32
          ",\"arbitration_lost\":%" PRIu32 ",\"fault_alerts\":%" PRIu32 ",\"bounded_retry\":true,"
          "\"uwb\":{\"transport\":\"%s\",\"radio_ready\":%s,\"configured\":%s,\"tag\":%u,\"observed\":%s,\"observed_tag\":%u,"
          "\"fresh\":%s,\"following\":%s,\"bearing\":%.1f,\"range_m\":%.2f,"
          "\"age_ms\":%" PRIu32 ",\"reports\":%" PRIu32 ",\"bad\":%" PRIu32 ","
          "\"direction\":%d,\"zero\":%.1f,\"max_speed\":%.1f,\"reason\":\"%s\"}}\n",
      static_cast<unsigned>(ManualControl::MaxSpeed / 10), now, sessionToken, motion.active() ? "true" : "false", canReady ? "true" : "false",
      fresh(now) ? "true" : "false", canReady && probing && fresh(now) && consecutiveReplies >= 3 ? "true" : "false",
      probing ? "true" : "false", joint.yaw, joint.roll, joint.pitch,
      outputPan/10.0f, outputTilt/10.0f, validReplies, canReady ? motion.reason() : faultReason,
      s.bus_error_count, s.rx_missed_count, s.rx_overrun_count, s.rx_error_counter, s.tx_error_counter,
      s.tx_failed_count, s.arb_lost_count, faultAlerts,
#if RS5_UWB_WIRELESS
      "esp-now", espnowLink::ready ? "true" : "false",
#else
      "uart", "false",
#endif
      uwbConfigured ? "true" : "false", tracker.tag(),
      haveObservedTag && now - observedMs <= 300 ? "true" : "false", observedTag,
      tracker.fresh(now) ? "true" : "false", following ? "true" : "false",
      tracker.bearing(), tracker.distanceCm()/100.0f, tracker.age(now), uwbReports, uwbBad,
      uwbDirection, uwbZero/10.0f, uwbMaxSpeed/10.0f,
      tracker.age(now) > 300 && tracker.age(now) != UINT32_MAX ? "tag stale" : tracker.reason());
}
static void help() {
  logLine("RS5 MANUAL CONTROL protocol=2 | CAN 1Mbit/s | TX=5 RX=6 | boots disarmed\n");
  logLine("probe | stop | idle | status | arm TOKEN CLOCK | drive TOKEN CLOCK SEQ PAN TILT\n");
#if RS5_UWB_WIRELESS
  logLine("UWB ESP-NOW | body mac=%s radio_ready=%d | channel=%u\n",
      WiFi.macAddress().c_str(), espnowLink::ready, wirelessConfig::Channel);
#else
  logLine("UWB RX=38 115200\n");
#endif
  logLine("uwb TOKEN CLOCK TAG SIGN ZERO MAX | track TOKEN CLOCK | follow TOKEN CLOCK SEQ\n");
}
static bool unsignedValue(const char *text, uint32_t &out) {
  if (!text || !*text) return false;
  for (const char *p = text; *p; ++p) if (*p < '0' || *p > '9') return false;
  errno = 0; char *end = nullptr;
  const unsigned long value = strtoul(text, &end, 10);
  if (errno || *end || value > UINT32_MAX) return false;
  out = static_cast<uint32_t>(value); return true;
}
static bool speedValue(const char *text, int &out) {
  if (!text || !*text) return false;
  errno = 0; char *end = nullptr;
  const long value = strtol(text, &end, 10);
  if (errno || *end || value < -ManualControl::MaxSpeed || value > ManualControl::MaxSpeed) return false;
  out = static_cast<int>(value); return true;
}
static void handleCommand(char *line, uint32_t now) {
  if (!strcmp(line, "help")) { help(); return; }
  if (!strcmp(line, "status")) { status(now); return; }
  if (!strcmp(line, "stop") || !strcmp(line, "idle")) {
    stopMotion("operator_stop");
    if (!strcmp(line, "idle")) probing = queryPending = false;
    status(millis()); return;
  }
  if (!strcmp(line, "probe")) {
    stopMotion("probing");
    if (!canReady) { logLine("REFUSED reset required after CAN fault\n"); return; }
    probing = true; haveJoint = queryPending = false; consecutiveReplies = 0;
    parser.reset(); querySentMs = now - QueryMs;
    return;
  }
  char *args[7] = {}; unsigned count = 0; char *save = nullptr;
  for (char *p = strtok_r(line, " ", &save); p; p = strtok_r(nullptr, " ", &save)) {
    if (count == 7) { stopMotion("invalid_command"); return; }
    args[count++] = p;
  }
  uint32_t token = 0, stamp = 0, number = 0;
  if (count < 3 || !unsignedValue(args[1], token) || !unsignedValue(args[2], stamp) ||
      token != sessionToken || now - stamp > 300) {
    stopMotion("stale_command"); return;
  }
  int sign = 0, zero = 0, maximum = 0;
  uint32_t tag = 0;
  if (count == 7 && !strcmp(args[0], "uwb") && unsignedValue(args[3], tag) && tag <= 65535 &&
      speedValue(args[4], sign) && (sign == 1 || sign == -1) &&
      speedValue(args[5], zero) && abs(zero) <= 300 &&
      speedValue(args[6], maximum) && maximum >= 10 && maximum <= 300) {
    stopMotion("uwb_configured");
    uwbDirection = sign; uwbZero = zero; uwbMaxSpeed = maximum;
    tracker.configure(zero/10.0f, maximum/10.0f); tracker.select(static_cast<uint16_t>(tag));
    uwbConfigured = true;
    status(millis()); return;
  }
  const bool startFollow = count == 3 && !strcmp(args[0], "track");
  if (count == 3 && (!strcmp(args[0], "arm") || startFollow)) {
    if (!canReady || !probing || !fresh(now) || consecutiveReplies < 3 || !Serial ||
        (startFollow && (!uwbConfigured || !tracker.fresh(now))) ||
        !motion.arm(now, joint.yaw, joint.roll, joint.pitch)) {
      stopMotion("enable_refused"); status(millis()); return;
    }
    following = startFollow;
    outputPan = outputTilt = 0;
    tracker.restartOutput(now);
    lastControlMs = now - 50;
    status(now); return;
  }
  if (count == 4 && !strcmp(args[0], "follow") && following && unsignedValue(args[3], number)) {
    if (!tracker.fresh(now)) { stopMotion("uwb_lost"); return; }
    if (!motion.input(now, number, 0, 0)) stopMotion(motion.reason(), true);
    return;
  }
  int pan = 0, tilt = 0;
  if (count == 6 && !strcmp(args[0], "drive") && !following && unsignedValue(args[3], number) &&
      speedValue(args[4], pan) && speedValue(args[5], tilt)) {
    const bool wasActive = motion.active();
    if (!motion.input(now, number, pan, tilt)) {
      if (wasActive) stopMotion(motion.reason(), true);
      return;
    }
    // Zero input stops on this iteration, without waiting for the next 50ms tick.
    if (pan == 0 && tilt == 0) lastControlMs = now - 50;
    return;
  }
  stopMotion("invalid_command");
}
static void invalidateUwb(const char *reason) {
  ++uwbBad; tracker.invalidate(reason);
  if (following) stopMotion(reason);
}
static void readUwb(uint32_t now, bool stalled) {
#if RS5_UWB_WIRELESS
  espnowLink::Message message; bool lost = false;
  const bool available = espnowLink::take(message, lost);
  if (stalled || lost) {
    radioReceiver.cancel(); invalidateUwb("uwb_radio_overrun");
  } else if (available) {
    uwb::Measurement m; uint32_t sampleMs = 0;
    const auto result = radioReceiver.accept(message.bytes, message.size, now, m, sampleMs);
    if (result == wireless::Result::Restart) {
      invalidateUwb("uwb_radio_restart"); tracker.reset();
    } else if (result == wireless::Result::Invalid) invalidateUwb("uwb_radio_invalid");
    else if (result == wireless::Result::Measurement) {
      ++uwbReports; observedTag = m.tag; observedMs = sampleMs; haveObservedTag = true;
      tracker.update(m, sampleMs);
      if (following && !tracker.fresh(now)) stopMotion("uwb_lost");
    }
  }
  if (espnowLink::ready && now - lastPollMs >= wireless::PollMs) {
    uint8_t request[wireless::RequestSize];
    radioReceiver.request(now, request); lastPollMs = now;
    if (!espnowLink::send(request, sizeof(request))) {
      radioReceiver.cancel(); invalidateUwb("uwb_radio_send");
    }
  }
#else
  if (uartError || stalled || Serial1.available() > 512) {
    uartError = false;
    for (unsigned i = 0; i < 2048 && Serial1.available(); ++i) Serial1.read();
    uwbParser.reset(); invalidateUwb("uwb_overrun"); return;
  }
  if (uwbParser.expire(now)) invalidateUwb("uwb_incomplete");
  for (unsigned i = 0; i < 512 && Serial1.available(); ++i) {
    uwb::Measurement m;
    const auto result = uwbParser.feed(Serial1.read(), now, m);
    if (result == uwb::ParseResult::Invalid) invalidateUwb("uwb_invalid");
    if (result == uwb::ParseResult::Measurement) {
      ++uwbReports; observedTag = m.tag; observedMs = now; haveObservedTag = true;
      tracker.update(m, now);
      if (following && !tracker.fresh(now)) stopMotion("uwb_lost");
    }
  }
#endif
}
static void readCommands() {
  for (unsigned i = 0; i < 128 && Serial.available(); ++i) {
    const char c = Serial.read();
    if (c == '\r') continue;
    if (c == '\n') {
      if (!badCommand && commandLength) {
        command[commandLength] = 0;
        handleCommand(command, millis());
      }
      commandLength = 0; badCommand = false;
    } else if (!badCommand) {
      if (c < 32 || c > 126 || commandLength + 1 >= sizeof(command)) {
        badCommand = true; stopMotion("invalid console input");
      } else command[commandLength++] = c;
    }
  }
}
static void readCan() {
  if (!canReady) return;
  uint32_t alerts = 0;
  if (twai_read_alerts(&alerts, 0) == ESP_OK && !checkAlerts(alerts)) return;
  for (unsigned i = 0; i < 128; ++i) {
    twai_message_t frame = {};
    const esp_err_t result = twai_receive(&frame, 0);
    if (result == ESP_ERR_TIMEOUT) break;
    if (result != ESP_OK) { canFault("receive failed"); return; }
    ++received;
    if (frame.extd || frame.rtr || frame.identifier != dji::RxCanId || frame.data_length_code > 8) continue;
    const uint32_t now = millis();
    for (unsigned b = 0; b < frame.data_length_code; ++b) {
      dji::Packet packet;
      if (parser.feed(frame.data[b], now, packet) && queryPending && now - querySentMs <= JointTimeoutMs &&
          dji::jointReply(packet, querySequence, joint)) {
        haveJoint = true; queryPending = false; jointMs = now;
        ++validReplies; if (consecutiveReplies < 3) ++consecutiveReplies;
      }
    }
  }
}
void setup() {
  sessionToken = esp_random();
  gpio_set_level(CanTx, 1); gpio_set_direction(CanTx, GPIO_MODE_OUTPUT);
  gpio_set_pull_mode(CanTx, GPIO_PULLUP_ONLY);
  pinMode(static_cast<uint8_t>(CanRx), INPUT_PULLUP);
  Serial.begin(115200);
#if RS5_UWB_WIRELESS
  espnowLink::begin(false);
  radioReceiver.begin(esp_random());
#else
  Serial1.setRxBufferSize(1024);
  Serial1.begin(115200, SERIAL_8N1, 38, 39); // RX pad; TX/GPIO39 stays unconnected.
  Serial1.onReceiveError([](hardwareSerial_error_t error) {
    if (error != UART_NO_ERROR) uartError = true;
  });
#endif
#if ARDUINO_USB_CDC_ON_BOOT
  Serial.setTxTimeoutMs(0);
#endif
  twai_general_config_t config = TWAI_GENERAL_CONFIG_DEFAULT(CanTx, CanRx, TWAI_MODE_NORMAL);
  config.tx_queue_len = 8; config.rx_queue_len = 256;
  config.alerts_enabled = FaultAlerts | TWAI_ALERT_ARB_LOST;
  const twai_timing_config_t timing = TWAI_TIMING_CONFIG_1MBITS();
  const twai_filter_config_t filter = TWAI_FILTER_CONFIG_ACCEPT_ALL();
  if (twai_driver_install(&config, &timing, &filter) == ESP_OK) {
    canReady = true;
    if (twai_start() != ESP_OK) canFault("start failed");
  } else canFault("install failed");
  help();
  lastLoopMs = millis();
}
void loop() {
  const bool stalled = millis() - lastLoopMs > 100;
  lastLoopMs = millis();
  readCan();
  // Evaluate expiry before draining serial so queued input cannot revive a lease.
  uint32_t now = millis();
  bool wasActive = motion.active();
  motion.tick(now, joint.yaw, joint.roll, joint.pitch, fresh(now), !!Serial);
  if (wasActive && !motion.active()) stopMotion(motion.reason(), true);
  // Expire the old fix before accepting buffered UART or wireless reports.
  if (following && !tracker.fresh(now)) stopMotion("uwb_lost");
  readUwb(now, stalled);
  if (!Serial) probing = queryPending = false;
  readCommands();
  now = millis();
  wasActive = motion.active();
  motion.tick(now, joint.yaw, joint.roll, joint.pitch, fresh(now), !!Serial);
  if (wasActive && !motion.active()) stopMotion(motion.reason(), true);
  if (canReady && motion.active() && now - lastControlMs >= 50) {
    lastControlMs = now;
    if (following && !tracker.fresh(now)) stopMotion("uwb_lost");
    else {
      outputPan = following ? static_cast<int16_t>(lroundf(tracker.step(now) * uwbDirection * 10)) : motion.yaw();
      outputTilt = following ? 0 : motion.pitch();
      sendPacket(dji::axisSpeed(++sequence, outputPan, outputTilt, true));
    }
  }
  now = millis();
  if (canReady && probing) {
    if (queryPending && now - querySentMs > JointTimeoutMs) {
      queryPending = false; consecutiveReplies = 0; parser.reset();
    }
    if (!queryPending && now - querySentMs >= QueryMs) {
      querySequence = ++sequence; querySentMs = now;
      queryPending = sendPacket(dji::jointQuery(querySequence));
    }
  }
  now = millis();
  if (now - lastReportMs >= 50) { status(now); lastReportMs = now; }
  drainConsole();
  delay(1);
}

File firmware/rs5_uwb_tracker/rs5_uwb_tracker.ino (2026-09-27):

// Adafruit Feather ESP32-S3, 8 MB/no PSRAM, Makerfabs Gen1 STM32 AoA, DJI RS5.
// Anchor TXD1/PA9 -> Feather RX/GPIO38; anchor GND -> Feather GND.
// Waveshare CAN TX <- Feather 5; CAN RX -> Feather 6; 3.3V <- Feather 3V.
// Anchor and Feather each use their own USB supply; only signal grounds join.

#include <Arduino.h>
#include <driver/gpio.h>
#include <driver/twai.h>
#include <esp_err.h>
#include <inttypes.h>
#include <stdarg.h>
#include "ConsoleQueue.h"
#include "DjiProtocol.h"
#include "MakerfabsProtocol.h"
#include "TrackingCore.h"

#if !defined(CONFIG_IDF_TARGET_ESP32S3)
#error "This firmware targets the Adafruit Feather ESP32-S3 No PSRAM."
#endif
#ifndef RS5_ENABLE_MOTION
#define RS5_ENABLE_MOTION 0
#endif
#if RS5_ENABLE_MOTION != 0 && RS5_ENABLE_MOTION != 1
#error "RS5_ENABLE_MOTION must be 0 or 1."
#endif

static constexpr gpio_num_t CanTx = GPIO_NUM_5, CanRx = GPIO_NUM_6;
static constexpr int UwbRx = 38, UnconnectedUartTx = 39;
static constexpr uint32_t ControlPeriodMs = 50, QueryPeriodMs = 200;
static constexpr uint32_t JointTimeoutMs = 500;
static constexpr float JointLimitDegrees = 85.0f;
static constexpr uint32_t CanAlerts = TWAI_ALERT_BUS_ERROR | TWAI_ALERT_BUS_OFF |
                                      TWAI_ALERT_RX_QUEUE_FULL | TWAI_ALERT_RX_FIFO_OVERRUN |
                                      TWAI_ALERT_TX_FAILED;

static tracking::Tracker tracker;
static uwb::StreamParser uwbParser;
static dji::StreamParser djiParser;
static ConsoleQueue<4096> consoleQueue;
static bool canReady = false, activeCan = false, armed = false;
static bool haveJoint = false, queryPending = false;
static int direction = 1;
static uint16_t packetSequence = 0, querySequence = 0;
static uint32_t querySentMs = 0, jointReceivedMs = 0;
static uint32_t lastControlMs = 0, lastReportMs = 0, lastLoopMs = 0;
static uint32_t uwbReports = 0, badReports = 0, canFrames = 0;
static uint32_t droppedLogs = 0;
static dji::JointAngles joint;
static float requestedSpeed = 0;
static volatile bool uartError = false;
static char commandLine[64];
static size_t commandLength = 0;
static bool discardCommand = false;

static void logLine(const char *format, ...) {
  char line[256];
  va_list args;
  va_start(args, format);
  const int length = vsnprintf(line, sizeof(line), format, args);
  va_end(args);
  if (length <= 0 || length >= static_cast<int>(sizeof(line)) ||
      !Serial || !consoleQueue.append(line, static_cast<size_t>(length))) ++droppedLogs;
}

static void drainConsole() {
  if (!Serial || !consoleQueue.size()) return;
  const int available = Serial.availableForWrite();
  if (available <= 0) return;
  size_t length = consoleQueue.contiguousSize();
  if (length > static_cast<size_t>(available)) length = available;
  consoleQueue.consume(Serial.write(consoleQueue.data(), length));
}

static void stopDriver() {
  if (canReady) {
    twai_stop();
    twai_driver_uninstall();
  }
  canReady = activeCan = armed = haveJoint = queryPending = false;
  djiParser.reset();
  gpio_set_level(CanTx, 1);
  gpio_set_direction(CanTx, GPIO_MODE_OUTPUT);
}

static void canFault(const char *operation, esp_err_t error) {
  // Stopping clears queued commands. No automatic retry or motion re-arming.
  stopDriver();
  requestedSpeed = 0;
  logLine("CAN FAULT %s: %s; driver stopped, motion disarmed. Fix wiring before probe/listen.\n",
          operation, esp_err_to_name(error));
}

static bool startCan(bool active) {
  stopDriver();
#if !RS5_ENABLE_MOTION
  if (active) return false;
#endif
  twai_general_config_t general = TWAI_GENERAL_CONFIG_DEFAULT(
      CanTx, CanRx, active ? TWAI_MODE_NORMAL : TWAI_MODE_LISTEN_ONLY);
  general.tx_queue_len = active ? 8 : 0;
  general.rx_queue_len = 64;
  general.alerts_enabled = CanAlerts;
  const twai_timing_config_t timing = TWAI_TIMING_CONFIG_1MBITS();
  const twai_filter_config_t filter = TWAI_FILTER_CONFIG_ACCEPT_ALL();
  esp_err_t result = twai_driver_install(&general, &timing, &filter);
  if (result != ESP_OK) { canFault("install", result); return false; }
  canReady = true;
  result = twai_start();
  if (result != ESP_OK) { canFault("start", result); return false; }
  activeCan = active;
  logLine("CAN %s at 1 Mbit/s. Motion is DISARMED.\n", active ? "QUERY MODE (normal CAN)" : "LISTEN ONLY");
  return true;
}

static bool sendPacket(const dji::Packet &packet) {
#if RS5_ENABLE_MOTION
  if (!canReady || !activeCan || packet.length == 0) return false;
  for (size_t offset = 0; offset < packet.length; offset += 8) {
    twai_message_t frame = {};
    frame.identifier = dji::TxCanId;
    frame.ss = 1;  // Each CAN frame gets one attempt; never queue endless retries.
    const size_t remaining = packet.length - offset;
    frame.data_length_code = remaining > 8 ? 8 : remaining;
    memcpy(frame.data, packet.bytes + offset, frame.data_length_code);
    const esp_err_t result = twai_transmit(&frame, pdMS_TO_TICKS(5));
    if (result != ESP_OK) { canFault("transmit", result); return false; }
  }
  return true;
#else
  (void)packet;
  return false;
#endif
}

static void disarm(const char *reason) {
  const bool wasArmed = armed;
  armed = false;
  if (wasArmed && activeCan) {
    // Zero all speeds, then release speed control in CAN bus order.
    if (sendPacket(dji::yawSpeed(++packetSequence, 0, true))) {
      sendPacket(dji::yawSpeed(++packetSequence, 0, false));
    }
  }
  if (wasArmed) logLine("DISARMED: %s. Re-arm explicitly after checking the cause.\n", reason);
}

static bool jointFresh(uint32_t now) {
  return haveJoint && now - jointReceivedMs <= JointTimeoutMs;
}

static void printHelp() {
  logLine("RS5 UWB tracker | Feather ESP32-S3 No PSRAM | CAN TX=5 RX=6 | UWB RX=38 (RX pad)\n");
  logLine("Build=%s. Startup always listen-only/disarmed. Anchor must turn with lens.\n",
          RS5_ENABLE_MOTION ? "MOTION-CAPABLE" : "PREVIEW ONLY");
  logLine("Commands (newline): tag HHHH | status | help | stop | listen | probe | arm + | arm -\n");
  logLine("tag selects the anchor's a16. probe sends joint-angle queries in a motion-capable build.\n");
  logLine("arm +/- selects calibrated yaw direction. Loss of tag/CAN telemetry requires re-arming.\n");
}

static void printStatus(uint32_t now) {
  logLine("%s tag=%s%04X uwb=%" PRIu32 " bad=%" PRIu32 " state=%s bearing=%.1f range=%.2fm proposed=%.1fdeg/s\n",
          armed ? "ARMED" : "DISARMED", tracker.selected() ? "" : "unset/",
          tracker.tag(), uwbReports, badReports, tracker.reason(), tracker.bearing(),
          tracker.distanceCm() / 100.0f, requestedSpeed);
  logLine("CAN=%s frames=%" PRIu32 " joint=%s yaw=%.1f skipped_logs=%" PRIu32 "\n",
          canReady ? (activeCan ? "query/normal" : "listen-only") : "stopped",
          canFrames, jointFresh(now) ? "fresh" : "missing/stale", joint.yaw, droppedLogs);
}
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

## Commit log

2026-09-23 add base design for harness
    [rs2-carrier.scad, rs2-carrier.stl, rs2-millmax-base.stl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]
2026-09-23 add references back
    [rileyharmon-rs2-connector.stl]
2026-09-27 tag enclosure and initial firmware
    [enclosure.scad, fit-gauge.stl, front.stl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]
2026-10-01 now with uwb tracking
    [base.stl, cover.stl, enclosure.scad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]
2026-10-04 new we have no dangling wires from the camera directly
    [base.stl, board-insert-coupon.stl, cover.stl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]
2026-10-06 add tag case updates
    [enclosure.scad, front.stl, print-plate.stl]
